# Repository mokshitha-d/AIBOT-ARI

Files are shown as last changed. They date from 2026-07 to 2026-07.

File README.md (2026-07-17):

# AI Mini Bot — DIY Kit

Build your own tiny desk robot that **talks, looks around, remembers you, and can control your Mac**.

The **ESP32 is the body** (OLED face, camera, pan/tilt servos).  
Your **computer is the brain** (OpenAI Realtime voice + ElevenLabs + local memory + head tracking).

> Illustrated guide: open [`docs/build_guide.html`](docs/build_guide.html) in a browser.

---

## What you get

- Live voice conversation (OpenAI Realtime `gpt-realtime-2`)
- Cloned / chosen voice (ElevenLabs)
- Animated OLED face (15 expressions) + web **Face Deck** at `http://<bot-ip>/`
- Pan/tilt head via PCA9685 (AI tools + autonomous glance / scan / face track)
- Local semantic memory (stays on your machine)
- Optional Mac actions (search, notes, apps, system info)

---

## Parts list

| Part | Notes |
|---|---|
| Seeed **XIAO ESP32S3 Sense** | Must be **Sense** (onboard camera) |
| 0.96" **SSD1306** OLED (I²C) | 128×64 |
| **PCA9685** 16-ch PWM board | Drives servos |
| 2× **HG90 / SG90** servos | Base = pan, neck = tilt |
| **5V 3–4A** supply | Powers PCA9685 `V+` (not from the XIAO 3V3) |
| Mac (or Linux/Windows with mic) | Runs the Python brain |

### Wiring (short version)

| From | To |
|---|----|
| OLED VCC / GND | XIAO 3V3 / GND |
| OLED SDA / SCL | XIAO **D4** / **D5** |
| PCA9685 VCC / GND | XIAO 3V3 / GND (common ground with 5V brick) |
| PCA9685 SDA / SCL | Same bus: **D4** / **D5** |
| PCA9685 V+ | External **5V** servo supply |
| Servos | PCA **CH0 = pan**, **CH1 = tilt** |

Full notes: [`hardware/README.md`](hardware/README.md).

---

## 1. Flash the body

1. Arduino IDE → ESP32 boards package  
2. **Tools:** Board `XIAO_ESP32S3`, **PSRAM = OPI PSRAM**, USB CDC On Boot = Enabled  
3. Libraries: `Adafruit GFX`, `Adafruit SSD1306`, `Adafruit PWM Servo Driver`  
4. Open `firmware/bot_face/bot_face.ino` (keep `control_page.h` beside it)  
5. Set your Wi‑Fi SSID/password near the top  
6. Upload → Serial Monitor @ **115200** → note **Bot IP**  
7. Open `http://<bot-ip>/` → Face Deck + head controls  

If upload fails at high baud, set **Upload Speed = 115200** and hold **BOOT** while resetting.

Camera off? In the sketch set `#define ENABLE_CAMERA 0`.

---

## 2. Run the brain

```bash
cd brain
python3.11 -m venv ../venv
source ../venv/bin/activate   # Windows: ..\venv\Scripts\activate
pip install -r requirements.txt
```

Copy `.env.example` → `.env` and fill:

```bash
OPENAI_API_KEY=...        # needs Realtime API access
ELEVENLABS_API_KEY=...
```

Edit `brain/bot_brain.py`:

```python
BOT_IP   = "192.168.1.XX"           # from Serial Monitor
VOICE_ID = "YOUR_ELEVENLABS_VOICE_ID"
```

From the kit root:

```bash
./run.sh
# or:  cd brain && python bot_brain.py
```

---

## Repo layout

```
diy-kit/
  firmware/bot_face/   ESP32 body (face + servos + camera + web UI)
  brain/               Mac brain (Realtime, voice, memory, head tracking)
  hardware/            Wiring notes
  docs/                Build guide
  run.sh               Launcher
  .env.example         API key template
```

---

## How it thinks

```
[ ESP32 body ]                         [ your computer — brain ]
  OLED face                              hear → Realtime → reply text
  /set  /look  /capture   ←── Wi‑Fi ──→  ElevenLabs speaks
  Face Deck web UI                       memory + Mac tools
                                         head_controller (glance/scan/track)
```

The model can call tools (`set_face`, `look`, …). A separate head loop can glance, scan the room, and track faces from camera snapshots.

---

## Security

- Never commit `.env`, Wi‑Fi passwords, or API keys  
- `.gitignore` already excludes `.env`, `venv/`, and `bot_memory/`  
- Rotate any key that leaks  

---

## License

MIT — see [LICENSE](LICENSE). Fork it, build it, make it weird.

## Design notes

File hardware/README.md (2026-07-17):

# Hardware

Breadboard prototype for the AI Mini Bot body: OLED face, camera (on Sense), and pan/tilt head via **PCA9685**.

## Parts

| Part | Role |
|---|---|
| Seeed XIAO ESP32S3 **Sense** | Brain-facing body (Wi-Fi, camera, I²C master) |
| 0.96" SSD1306 OLED | Face |
| PCA9685 16-ch PWM board | Drives servos (I²C) |
| HG90 / SG90-class servos ×2 | Base = pan (L/R), neck = tilt (U/D) |
| 5V **3–4A** supply | Powers PCA9685 `V+` (servos) — do **not** power servos from the XIAO 3V3 |

## Wiring (breadboard)

```
XIAO 3V3  ──► breadboard 3V3 rail ──► OLED VCC
                                    ──► PCA9685 VCC (logic)
XIAO GND  ──► breadboard GND      ──► OLED GND
                                    ──► PCA9685 GND
                                    ──► 5V supply GND  (common ground!)

XIAO D4 (SDA) ──► OLED SDA + PCA9685 SDA
XIAO D5 (SCL) ──► OLED SCL + PCA9685 SCL

5V supply (+) ──► PCA9685 V+ / terminal block  (servo power only)
```

### Servo channels (firmware defaults)

| PCA9685 channel | Axis | Motion |
|---|---|---|
| **CH0** | pan | base left / right |
| **CH1** | tilt | neck up / down |

Change `SERVO_CH_PAN` / `SERVO_CH_TILT` in `firmware/bot_face/bot_face.ino` if your plugs differ.

### Angles

| Pose | pan | tilt |
|---|-----|---|
| Neutral (looking at you) | 90 | 90 |
| Soft limits (first test) | 0–180 | 0–180 |

If left/right or up/down feel inverted after mounting, swap the mapping in firmware or reverse the mechanical horn.

## Power notes

- External **5V 3–4A** on the PCA9685 servo rail is required; USB alone will brown out under two HG90s.
- Keep **GND common** between XIAO, PCA9685, and the 5V brick.
- If the PCA9685 has an **OE** (output enable) pin, tie it to GND so outputs stay enabled.

## Test after flashing

1. Serial Monitor @ 115200 → note Bot IP; confirm `Servos: ready`
2. Browser: `http://<bot-ip>/` → use pan/tilt sliders + **center**
3. Or: `curl "http://<bot-ip>/look?pan=90&tilt=90"`

## 3D body

- **Model:** [`QBIT.3mf`](QBIT.3mf) (printable body)
- Optional: add a Printables / Thingiverse link here

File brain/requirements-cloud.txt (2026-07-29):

# cloud_server.py uses only the Python standard library — nothing to install.

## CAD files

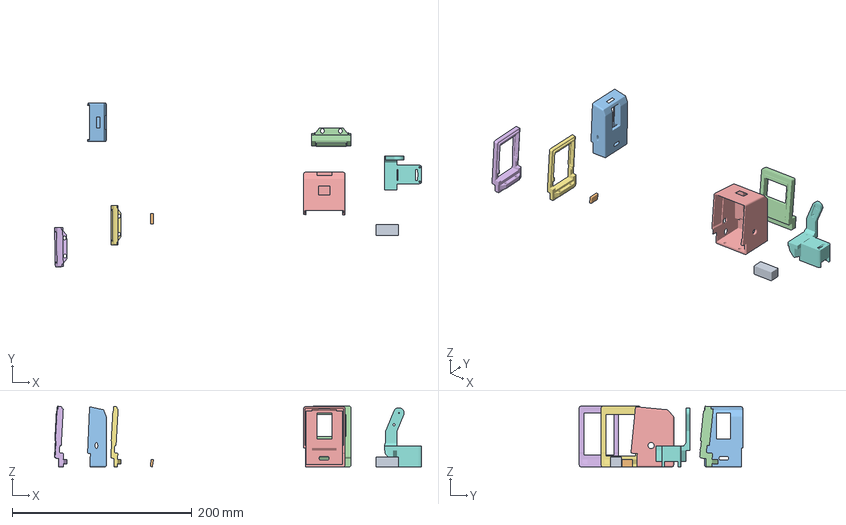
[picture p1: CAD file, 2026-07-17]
3D Model.3mf
407.9 x 182.0 x 67.4 mm
Generic-Cube_Boolean_Boolean
Generic-Cube_Boolean_Boolean_Boolean
Body_Back.stl_Boolean_Boolean_Boolean x 2
Shiny Stantia (1).stl x 3
Assembly_B_Boolean

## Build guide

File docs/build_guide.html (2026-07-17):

Open build guide · ESP32 + Mac

# A little robot that talks, sees, and remembers you.

A desk companion built from a coin-sized ESP32 with a camera and an OLED face. The board is the body; your computer is the brain. It holds a real conversation in a voice you choose, reacts to what its camera sees, remembers past chats, and can act on your Mac.

◉ Live voice

◉ Camera vision

◉ Cloned voice

◉ Long-term memory

◉ Animated face

◉ Controls your Mac

neutral

happy

thinking

searching

loading

z z

sleep

↑ the same faces the robot draws on its OLED, running live here

01

## How it works

The split that makes the whole thing possible.

The ESP32 can't run a large language model — nowhere near. So it doesn't try. The board handles the physical parts: it draws the animated face on the OLED and takes a photo when asked. Everything intelligent — hearing you, thinking, choosing words, remembering — runs in a Python program on your Mac. The two talk over your Wi-Fi.

The body

#### XIAO ESP32S3

- Draws the OLED face (15 expressions)
- Onboard camera → one photo on request
- Two tiny web endpoints: set the face, grab a frame
- Sits on your desk, powered by USB

emotion ← ⇄ → photo Wi-Fi

The brain

#### Your Mac (Python)

- Hears you, thinks, and replies as text
- Speaks the reply in a cloned voice
- Remembers every conversation, locally
- Can search, take notes, open apps, check the system

Why turn-based, not a live callThe robot listens, then speaks, with its microphone muted while it talks. This is deliberate: on laptop speakers, a fully live voice hears its own voice and cuts itself off mid-sentence. Waiting its turn is what keeps it from tripping over itself. More on this in the gotchas.

02

## What you'll need

A short list. The board does most of the heavy lifting.

Part | What it's for | Notes
Seeed XIAO ESP32S3 Sense | The whole body — Wi-Fi, camera, microphone-capable | Must be the "Sense" version — it has the camera
0.96" OLED display | The face | SSD1306, I²C, 4 pins (VCC/GND/SDA/SCL), 128×64
4 jumper wires | OLED → board | Female–female, or solder direct
USB-C cable | Power + flashing | A solid one — cheap cables cause boot brownouts
A 3D-printed body | Holds it all together | Model linked below
A Mac | The brain | Runs the Python program
Headphones (optional) | Cleaner conversations | Removes speaker→mic echo entirely

Accounts you'll needAn OpenAI key with Realtime access (the thinking + hearing), and an ElevenLabs key (the voice). Both have paid tiers — Realtime bills for audio, and a custom cloned voice via the API needs a paid ElevenLabs plan. Memory is fully local and free.

03

## Wiring the face

Four wires. The camera is already onboard — nothing to connect.

The OLED talks to the board over I²C, which needs just two data lines plus power. On the XIAO, the default I²C pins are D4 and D5.

OLED VCC

→

3V3

power

OLED GND

→

GND

ground

OLED SDA

→

D4

GPIO5 · data

OLED SCL

→

D5

GPIO6 · clock

Soldering the headerMost OLEDs ship with a loose 4-pin header. Push the pins through from the back so they poke out the labelled front, tape it flush, solder the two outer pins first, check it sits straight, then do the middle two. Insulate each joint and power-test before mounting anything into the body.

04

## Flashing the body

Load the firmware onto the ESP32 with the Arduino IDE.

### Board setup

Install the ESP32 boards package in the Arduino IDE, then set these under Tools — they matter, especially the PSRAM one:

Board | XIAO_ESP32S3
PSRAM | OPI PSRAM — required, or the camera fails to start
USB CDC On Boot | Enabled — so you get serial output

Install two libraries from the Library Manager: Adafruit GFX and Adafruit SSD1306.

### Set your Wi-Fi, then upload

Open bot_face_phase3a.ino, put in your network name and password near the top, and upload.

const char* ssid     = "your-wifi-name";
const char* password = "your-wifi-password";

Open the Serial Monitor. When it connects, it prints the robot's address — write it down, the brain needs it:

Connecting to WiFi....
Bot IP: 192.168.1.XX
Camera: ready

### Check it before moving on

Open http://<that-ip>/ in a browser. You get a little control page — tap the face buttons and watch the OLED switch expressions, and hit look to confirm the camera returns a photo. If both work, the body is done.

05

## Setting up the brain

Three Python files on your Mac do the thinking, remembering, and acting.

bot_brain_realtime.py | The main loop — hears you, thinks, speaks, drives the face
memory.py | Local semantic memory — saves and recalls past conversations
robot_actions.py | Mac actions — search, notes, open apps, system info

### Install & keys

Use a Python 3.11 environment, then:

# from the folder with the three files
python3.11 -m venv venv
source venv/bin/activate
pip install openai elevenlabs sounddevice httpx fastembed numpy

# your keys (they reset each terminal session)
export OPENAI_API_KEY="..."
export ELEVENLABS_API_KEY="..."

### Point it at your robot & voice

Near the top of bot_brain_realtime.py, set two things — the address from the Serial Monitor, and the ID of a voice you cloned in the ElevenLabs dashboard:

BOT_IP    = "192.168.1.XX"   # from Serial Monitor
VOICE_ID  = "your-cloned-voice-id"

### Run it

python bot_brain_realtime.py

First run downloads a small memory model (once), then it's listening. Everything it does prints to the console with timestamps — you can watch it hear you, look, think, and reply:

[LISTEN] you started talking
[STT]    you said: 'what time is it?'
[MEMORY] recalled 2 item(s)
[CAMERA] frame captured (10930 bytes)
[BOT]    It's just past 9 in the evening.

Keep it in one folderAll three files, and everything you run, live in a single folder. Scattered copies with the same name in different folders is the single biggest time-sink in a project like this — you edit one and run another and chase a bug that isn't there.

06

## What it can do

Beyond talking — and each action has its own face.

Say something like… | It does | Face
"Remember I train on Mondays" | Saves it to long-term memory | memory
"What did we talk about before?" | Recalls relevant past chats | memory
"Search the web for the XIAO datasheet" | Opens a browser search | searching
"Save a note about this idea" | Writes a markdown note | saving
"Open Spotify" | Launches the app | loading
"How's my laptop doing?" | Battery, storage, CPU, memory | scanning
"What's my Wi-Fi?" | Network name + IP | wifi

Memory is stored locally in plain files you can read. Mac actions run as your normal user — no admin needed — and the app-opening list is a whitelist you control.

07

## Hard-won lessons

The things that cost hours. Skip the pain.

#### The robot talks over itself

A fully live voice on laptop speakers hears its own audio through the mic and cuts off mid-sentence. Fix: mute the mic while it speaks (built in), or use headphones. Physically separating the mic and speaker is the real cure.

#### Camera won't start

"frame buffer malloc failed" means PSRAM is off. Set OPI PSRAM in the board menu and re-flash. Cold-boot flicker is usually weak USB power — use a good cable.

#### Camera image is upside down

Depends how the sensor sits. One line in the firmware flips it (set_vflip / set_hmirror). Check the photo in a browser at /capture.

#### Ghost file copies

Editing one file while running another with the same name in a different folder. One folder, one copy of each file, always.

#### The face won't change

Tap a face on the control page — if the status text updates but the OLED doesn't, it's the display; if the text doesn't update, it's the network or a wrong IP (check the Serial baud rate matches).

#### Two microphones fight

On macOS, opening the mic twice gives the second one silence. If you add wake-word or extra audio, share one mic stream.

08

## Files & links

Everything you need to build your own.

Source code (https://github.com/AyhanSh/Mac-AI-Buddy)

GitHub repo →

Firmware + the three Python files, ready to clone.

AyhanSh/Mac-AI-Buddy

3D model

Printable body →

The enclosure that holds the board and OLED.

add link

See it run

Demo video →

The robot talking, reacting, and changing faces.

add link

Before you publish your ownNever commit your Wi-Fi password or API keys. Keep them in a local .env or as environment variables, and add that file to .gitignore. If a key has ever been pasted somewhere shared, rotate it.

AI MINI BOT — open build guide

ESP32 body · Mac brain · built in public

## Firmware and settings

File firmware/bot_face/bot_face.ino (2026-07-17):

/*
  AI Mini Bot - Face + camera + pan/tilt head (PCA9685)

  Board:   Seeed XIAO ESP32S3 Sense
  Display: 0.96" SSD1306 OLED, I2C, addr 0x3C  (VCC->3V3 GND->GND SDA->D4 SCL->D5)
  Camera:  onboard OV2640 (Sense variant)
  Servos:  HG90 / SG90-class via PCA9685 on the SAME I2C bus (D4/D5)
           - external 5V 3–4A supply to PCA9685 V+ / GND
           - PCA9685 VCC -> 3V3, GND common with XIAO
           - default channels: CH0 = pan (base L/R), CH1 = tilt (neck U/D)

  Endpoints:
      GET /capture              -> single JPEG frame
      GET /look?pan=90&tilt=90  -> set head angles (0–180)
      GET /look/center          -> pan=90, tilt=90
      GET /look/status          -> current angles JSON

  Why snapshot-on-demand instead of continuous streaming:
  Running the MJPEG stream constantly alongside the OLED (I2C) and WiFi is what
  caused the DMA/resource conflicts on the intruder-alarm build. Grabbing ONE
  frame only when the Mac brain asks for it keeps the camera idle the rest of
  the time, so there's nothing to fight over.

  REQUIRED board settings:
    Board: XIAO_ESP32S3 (Sense)
    Tools > PSRAM: OPI PSRAM
    Tools > USB CDC On Boot: Enabled

  Libraries: Adafruit GFX, Adafruit SSD1306, Adafruit PWM Servo Driver

  Test after upload:
    - Serial Monitor @ 115200 for the IP
    - curl "http://<ip>/look?pan=90&tilt=90"
    - curl http://<ip>/capture --output test.jpg
    - http://<ip>/ face page + head sliders
*/

#include <Wire.h>
#include <Adafruit_GFX.h>
#include <Adafruit_SSD1306.h>
#include <Adafruit_PWMServoDriver.h>
#include <WiFi.h>
#include <WebServer.h>
#include "esp_camera.h"
#include <string.h>
#include "control_page.h"

// Set to 0 while the Sense camera is out of commission (servos/OLED still work).
#define ENABLE_CAMERA  1

// ---------- display ----------
#define SCREEN_WIDTH  128
#define SCREEN_HEIGHT 64
#define OLED_ADDR     0x3C
Adafruit_SSD1306 display(SCREEN_WIDTH, SCREEN_HEIGHT, &Wire, -1);

// ---------- wifi ----------
const char* ssid     = "YOUR_WIFI_SSID";     // <-- your network
const char* password = "YOUR_WIFI_PASSWORD";   // <-- fill this in
WebServer server(80);

// ---------- camera pins (XIAO ESP32S3 Sense) ----------
#define PWDN_GPIO_NUM     -1
#define RESET_GPIO_NUM    -1
#define XCLK_GPIO_NUM     10
#define SIOD_GPIO_NUM     40
#define SIOC_GPIO_NUM     39
#define Y9_GPIO_NUM       48
#define Y8_GPIO_NUM       11
#define Y7_GPIO_NUM       12
#define Y6_GPIO_NUM       14
#define Y5_GPIO_NUM       16
#define Y4_GPIO_NUM       18
#define Y3_GPIO_NUM       17
#define Y2_GPIO_NUM       15
#define VSYNC_GPIO_NUM    38
#define HREF_GPIO_NUM     47
#define PCLK_GPIO_NUM     13

bool cameraReady = false;
bool oledReady = false;

// ---------- head servos (PCA9685 @ 0x40 on shared I2C) ----------
// Change CH_* if your breadboard plugs pan/tilt into different PCA slots.
#define PCA9685_ADDR   0x40
#define SERVO_CH_PAN   0      // base: left / right
#define SERVO_CH_TILT  1      // neck: up / down
#define SERVO_US_MIN   500    // HG90 / SG90-ish full travel
#define SERVO_US_MAX   2500
#define PAN_CENTER     90
#define TILT_CENTER    90
#define PAN_MIN        0
#define PAN_MAX        180
#define TILT_MIN       0
#define TILT_MAX       180

Adafruit_PWMServoDriver pca = Adafruit_PWMServoDriver(PCA9685_ADDR, Wire);
bool servosReady = false;
int currentPan  = PAN_CENTER;
int currentTilt = TILT_CENTER;

// ---------- emotion state ----------
enum Emotion { NEUTRAL, HAPPY, SAD, ANGRY, SURPRISED, THINKING, LISTENING, TALKING, SLEEP,
               SEARCHING, LOADING, SCANNING, WIFI, MEMORY, SAVING };
Emotion current = NEUTRAL;

// ---------- timing ----------
unsigned long lastFrame = 0;
const int FRAME_MS = 33;

// ---------- blink ----------
bool blinking = false;
unsigned long blinkStart = 0;
unsigned long nextBlink = 0;
const int BLINK_MS = 180;

// ---------- geometry ----------
const int CX = 64, CY = 32;
const int EYE_W = 34, EYE_H = 40, EYE_R = 10;
const int EYE_GAP = 20;

float blinkOpenness() {
  if (!blinking) return 1.0;
  unsigned long e = millis() - blinkStart;
  if (e >= (unsigned long)BLINK_MS) { blinking = false; return 1.0; }
  float t = (float)e / BLINK_MS;
  return fabs(t - 0.5) * 2.0;
}

void drawOpenEyes(float hScale, int yOffset, int wDelta) {
  int h = (int)(EYE_H * hScale);
  if (h < 4) h = 4;
  int w = EYE_W + wDelta;
  int y  = CY - h / 2 + yOffset;
  int lx = CX - EYE_GAP / 2 - w;
  int rx = CX + EYE_GAP / 2;
  display.fillRoundRect(lx, y, w, h, EYE_R, SSD1306_WHITE);
  display.fillRoundRect(rx, y, w, h, EYE_R, SSD1306_WHITE);
}

void drawHappyEyes() {
  int r = 18, y = CY - 2;
  int lcx = CX - EYE_GAP / 2 - r;
  int rcx = CX + EYE_GAP / 2 + r;
  display.fillCircle(lcx, y, r, SSD1306_WHITE);
  display.fillCircle(rcx, y, r, SSD1306_WHITE);
  display.fillRect(0, y, SCREEN_WIDTH, r + 3, SSD1306_BLACK);
}

void drawSurprisedEyes() {
  int r = 19;
  int lcx = CX - EYE_GAP / 2 - r + 3;
  int rcx = CX + EYE_GAP / 2 + r - 3;
  int y = CY;
  display.fillCircle(lcx, y, r, SSD1306_WHITE);
  display.fillCircle(rcx, y, r, SSD1306_WHITE);
  display.fillCircle(lcx, y, r / 2, SSD1306_BLACK);
  display.fillCircle(rcx, y, r / 2, SSD1306_BLACK);
}

void drawAngryEyes() {
  int h = 40, w = 34, y = CY - h / 2 + 2;
  int lx = CX - EYE_GAP / 2 - w;
  int rx = CX + EYE_GAP / 2;
  display.fillRoundRect(lx, y, w, h, EYE_R, SSD1306_WHITE);
  display.fillRoundRect(rx, y, w, h, EYE_R, SSD1306_WHITE);
  int cw = 26, ch = 20;
  display.fillTriangle(lx + w, y, lx + w - cw, y, lx + w, y + ch, SSD1306_BLACK);
  display.fillTriangle(rx,     y, rx + cw,     y, rx,     y + ch, SSD1306_BLACK);
}

void drawSadEyes() {
  int h = 30, w = 34, y = CY - h / 2 + 6;
  int lx = CX - EYE_GAP / 2 - w;
  int rx = CX + EYE_GAP / 2;
  display.fillRoundRect(lx, y, w, h, EYE_R, SSD1306_WHITE);
  display.fillRoundRect(rx, y, w, h, EYE_R, SSD1306_WHITE);
  int cw = 26, ch = 20;
  display.fillTriangle(lx,     y, lx + cw,     y, lx,     y + ch, SSD1306_BLACK);
  display.fillTriangle(rx + w, y, rx + w - cw, y, rx + w, y + ch, SSD1306_BLACK);
}

void drawThinkingEyes() {
  int h = 26, w = 34, xs = 6, ys = -4;
  int y  = CY - h / 2 + ys;
  int lx = CX - EYE_GAP / 2 - w + xs;
  int rx = CX + EYE_GAP / 2 + xs;
  display.fillRoundRect(lx, y, w, h, EYE_R, SSD1306_WHITE);
  display.fillRoundRect(rx, y, w, h, EYE_R, SSD1306_WHITE);
}

void drawSleepEyes() {
  int w = 34, y = CY;
  int lx = CX - EYE_GAP / 2 - w;
  int rx = CX + EYE_GAP / 2;
  display.fillRoundRect(lx, y - 2, w, 5, 2, SSD1306_WHITE);
  display.fillRoundRect(rx, y - 2, w, 5, 2, SSD1306_WHITE);
  display.setTextColor(SSD1306_WHITE);
  display.setTextSize(1);
  display.setCursor(98, 8);  display.print("z");
  display.setCursor(106, 0); display.print("z");
}

// shared: eyes with an x/y shift and height scale (used by the action faces)
void drawEyesShift(int xs, int ys, float hScale) {
  int h = (int)(EYE_H * hScale);
  if (h < 4) h = 4;
  int w = EYE_W;
  int y  = CY - h / 2 + ys;
  int lx = CX - EYE_GAP / 2 - w + xs;
  int rx = CX + EYE_GAP / 2 + xs;
  display.fillRoundRect(lx, y, w, h, EYE_R, SSD1306_WHITE);
  display.fillRoundRect(rx, y, w, h, EYE_R, SSD1306_WHITE);
}

// SEARCHING (web search): eyes dart side to side, scanning
void drawSearching() {
  int xs = (int)(14 * sin(millis() / 180.0));
  drawEyesShift(xs, 0, 0.8);
}

// LOADING (opening app / generic work): a comet-head spinner ring
void drawLoading() {
  int r = 16, dots = 12;
  int head = (int)(millis() / 80) % dots;
  for (int i = 0; i < dots; i++) {
    float a = (2 * PI * i) / dots;
    int x = CX + (int)(r * cos(a));
    int y = CY + (int)(r * sin(a));
    int dist = (i - head + dots) % dots;
    int rad = (dist == 0) ? 3 : (dist == 1 ? 2 : (dist == 2 ? 1 : 0));
    if (rad > 0) display.fillCircle(x, y, rad, SSD1306_WHITE);
  }
}

// SCANNING (system status): focused eyes + a scan bar sweeping across
void drawScanning() {
  drawEyesShift(0, 0, 0.55);
  int x = (int)(CX + 60 * sin(millis() / 300.0));
  display.drawFastVLine(x, 0, SCREEN_HEIGHT, SSD1306_WHITE);
}

// WIFI (network check): pulsing wifi arcs rising from a base dot
void drawWifi() {
  int by = 46;
  display.fillCircle(CX, by, 3, SSD1306_WHITE);
  int phase = (int)(millis() / 300) % 4;
  for (int k = 1; k <= 3; k++) {
    if (k <= phase) {
      int rr = k * 11;
      for (int deg = 225; deg <= 315; deg += 5) {
        float a = deg * PI / 180.0;
        int x = CX + (int)(rr * cos(a));
        int y = by + (int)(rr * sin(a));
        display.drawPixel(x, y, SSD1306_WHITE);
      }
    }
  }
}

// MEMORY (remember / recall / forget): eyes glance up, thought dots rise
void drawMemory() {
  drawEyesShift(-6, -3, 0.8);
  int phase = (int)(millis() / 250) % 3;
  int bx = 98, by = 22;
  for (int i = 0; i < 3; i++) {
    if (i <= phase) display.fillCircle(bx + i * 7, by - i * 7, (i == 2 ? 1 : 2), SSD1306_WHITE);
  }
}

// SAVING (save note): eyes + a cycling progress bar
void drawSaving() {
  drawEyesShift(0, -5, 0.7);
  int w = 80, x = (SCREEN_WIDTH - w) / 2, y = 52, h = 7;
  display.drawRoundRect(x, y, w, h, 2, SSD1306_WHITE);
  int fill = (int)(millis() / 18) % (w - 2);
  display.fillRect(x + 1, y + 1, fill, h - 2, SSD1306_WHITE);
}

void renderFace() {
  display.clearDisplay();
  switch (current) {
    case NEUTRAL:
      drawOpenEyes(blinkOpenness(), 0, 0);
      break;
    case LISTENING: {
      float pulse = 1.0 + 0.06 * sin(millis() / 250.0);
      drawOpenEyes(blinkOpenness() * pulse, 0, 2);
      break;
    }
    case TALKING: {
      int bob = (int)(2 * sin(millis() / 90.0));
      drawOpenEyes(blinkOpenness(), bob, 0);
      break;
    }
    case HAPPY:     drawHappyEyes();     break;
    case SAD:       drawSadEyes();       break;
    case ANGRY:     drawAngryEyes();     break;
    case SURPRISED: drawSurprisedEyes(); break;
    case THINKING:  drawThinkingEyes();  break;
    case SLEEP:     drawSleepEyes();     break;
    case SEARCHING: drawSearching();     break;
    case LOADING:   drawLoading();       break;
    case SCANNING:  drawScanning();      break;
    case WIFI:      drawWifi();          break;
    case MEMORY:    drawMemory();        break;
    case SAVING:    drawSaving();        break;
  }
  display.display();
}

void updateBlink() {
  if (current != NEUTRAL && current != LISTENING && current != TALKING) return;
  unsigned long now = millis();
  if (!blinking && now > nextBlink) {
    blinking = true;
    blinkStart = now;
    nextBlink = now + random(2500, 6000);
  }
}

// ---------- camera ----------
// 0x106 = ESP_ERR_NOT_SUPPORTED → sensor probe failed / bad config.
// Newer Arduino-ESP32 BSPs added fields to camera_config_t; leaving them
// uninitialized often causes exactly this. Zero the struct, keep SCCB on
// I2C port 1 so it never fights Wire (OLED + PCA9685 on port 0 / D4+D5).
bool initCameraOnce(int xclk_hz) {
  camera_config_t config;
  memset(&config, 0, sizeof(config));

  config.ledc_channel = LEDC_CHANNEL_0;
  config.ledc_timer   = LEDC_TIMER_0;
  config.pin_d0 = Y2_GPIO_NUM;  config.pin_d1 = Y3_GPIO_NUM;
  config.pin_d2 = Y4_GPIO_NUM;  config.pin_d3 = Y5_GPIO_NUM;
  config.pin_d4 = Y6_GPIO_NUM;  config.pin_d5 = Y7_GPIO_NUM;
  config.pin_d6 = Y8_GPIO_NUM;  config.pin_d7 = Y9_GPIO_NUM;
  config.pin_xclk  = XCLK_GPIO_NUM;
  config.pin_pclk  = PCLK_GPIO_NUM;
  config.pin_vsync = VSYNC_GPIO_NUM;
  config.pin_href  = HREF_GPIO_NUM;
  config.pin_sccb_sda = SIOD_GPIO_NUM;
  config.pin_sccb_scl = SIOC_GPIO_NUM;
  config.pin_pwdn  = PWDN_GPIO_NUM;
  config.pin_reset = RESET_GPIO_NUM;
  config.xclk_freq_hz = xclk_hz;
  config.pixel_format = PIXFORMAT_JPEG;
  config.frame_size   = FRAMESIZE_VGA;
  config.jpeg_quality = 12;
  config.grab_mode    = CAMERA_GRAB_WHEN_EMPTY;
#if defined(CAMERA_FB_IN_PSRAM)
  config.fb_location  = CAMERA_FB_IN_PSRAM;
#endif

  if (psramFound()) {
    config.fb_count = 2;
  } else {
    config.fb_count = 1;
  }

  esp_err_t err = esp_camera_init(&config);
  if (err != ESP_OK) {
    Serial.printf("Camera init failed: 0x%x (xclk=%dHz)\n", err, xclk_hz);
    return false;
  }
  return true;
}

bool initCamera() {
  Serial.printf("PSRAM: %s\n", psramFound() ? "found" : "NOT found (set Tools > PSRAM = OPI PSRAM)");
  delay(300);   // Sense cam ribbon is picky on cold boot / after upload

  // Single init only — esp_camera_init is effectively one-shot on many BSPs.
  if (!initCameraOnce(20000000)) {
    Serial.println("Camera probe failed (0x106 = sensor ID not recognized).");
    Serial.println("This is usually: loose Sense ribbon, OR Arduino ESP32 core 3.x bug.");
    Serial.println("Fix: reseat camera FPC, then try Boards Manager -> esp32 -> 2.0.14");
    return false;
  }

  sensor_t* s = esp_camera_sensor_get();
  if (s) {
    s->set_vflip(s, 1);    // flip vertically - fixes upside-down image
    s->set_hmirror(s, 0);  // set to 1 instead if it's mirrored left-right rather than upside-down
  }
  Serial.println("Camera: init ok");
  return true;
}

// ---------- servos ----------
int clampInt(int v, int lo, int hi) {
  if (v < lo) return lo;
  if (v > hi) return hi;
  return v;
}

int angleToUs(int angle) {
  angle = clampInt(angle, 0, 180);
  return SERVO_US_MIN + (angle * (SERVO_US_MAX - SERVO_US_MIN)) / 180;
}

void scanI2C() {
  Serial.println("I2C scan (D4=SDA, D5=SCL):");
  int n = 0;
  for (uint8_t addr = 1; addr < 127; addr++) {
    Wire.beginTransmission(addr);
    if (Wire.endTransmission() == 0) {
      Serial.printf("  found 0x%02X", addr);
      if (addr == OLED_ADDR) Serial.print("  (OLED)");
      if (addr == PCA9685_ADDR) Serial.print("  (PCA9685)");
      Serial.println();
      n++;
    }
  }
  if (n == 0) Serial.println("  nothing found — check 3V3/GND/SDA/SCL");
  Serial.println("Expect OLED 0x3C/0x3D + PCA 0x40. 0x70=PCA all-call OK. Ghost 0x01 => flaky bus/pull-ups.");
}


// Drive a channel with setPWM (more reliable across PCA9685 clones than us helpers).
void writeServoAngle(uint8_t ch, int angle) {
  int us = angleToUs(angle);
  // Prefer library us helper; also poke setPWM for stubborn clones.
  pca.writeMicroseconds(ch, us);
  uint16_t tick = (uint16_t)(((uint32_t)us * 4096UL) / 20000UL);
  if (tick < 1) tick = 1;
  if (tick > 4095) tick = 4095;
  pca.setPWM(ch, 0, tick);
  Serial.printf("servo CH%d -> %d deg (%dus / tick %u)\n", ch, angle, us, tick);
}

bool initServos() {
  // Older Adafruit_PWMServoDriver: begin(prescale=0). Address comes from the constructor.
  if (!pca.begin()) {
    Serial.println("PCA9685 not found on I2C - check wiring / address 0x40");
    return false;
  }
  // Cheap PCA9685 boards often need this or pulse widths are wrong / no motion.
  pca.setOscillatorFrequency(27000000);
  pca.setPWMFreq(50);   // hobby servo rate
  delay(20);

  currentPan  = PAN_CENTER;
  currentTilt = TILT_CENTER;
  writeServoAngle(SERVO_CH_PAN,  currentPan);
  writeServoAngle(SERVO_CH_TILT, currentTilt);
  delay(300);

  // Visible boot self-test — if you see no motion here, it's power/wiring/channel.
  Serial.println("Servo wiggle test (CH0 pan, CH1 tilt)...");
  writeServoAngle(SERVO_CH_PAN,  70);
  delay(250);
  writeServoAngle(SERVO_CH_PAN, 110);
  delay(250);
  writeServoAngle(SERVO_CH_PAN,  PAN_CENTER);
  writeServoAngle(SERVO_CH_TILT, 70);
  delay(250);
  writeServoAngle(SERVO_CH_TILT, 110);
  delay(250);
  writeServoAngle(SERVO_CH_TILT, TILT_CENTER);

  Serial.printf("Servos: ready (pan CH%d, tilt CH%d) centered at %d/%d\n",
                SERVO_CH_PAN, SERVO_CH_TILT, currentPan, currentTilt);
  Serial.println("If no wiggle: check 5V on PCA V+/terminal, common GND, OE low, servo plugs on CH0/CH1");
  return true;
}

void setHead(int pan, int tilt) {
  currentPan  = clampInt(pan,  PAN_MIN,  PAN_MAX);
  currentTilt = clampInt(tilt, TILT_MIN, TILT_MAX);
  if (!servosReady) return;
  writeServoAngle(SERVO_CH_PAN,  currentPan);
  writeServoAngle(SERVO_CH_TILT, currentTilt);
}

void handleCapture() {
  if (!cameraReady) {
    server.send(503, "text/plain", "camera not ready");
    return;
  }
  camera_fb_t* fb = esp_camera_fb_get();
  if (!fb) {
    server.send(500, "text/plain", "capture failed");
    return;
  }
  server.setContentLength(fb->len);
  server.send(200, "image/jpeg", "");
  WiFiClient client = server.client();
  client.write(fb->buf, fb->len);
  esp_camera_fb_return(fb);
}

void handleLook() {
  // Accept any combo of pan / tilt; missing args keep the current angle.
  Serial.printf("LOOK req args pan=%s tilt=%s\n",
                server.hasArg("pan") ? server.arg("pan").c_str() : "-",
                server.hasArg("tilt") ? server.arg("tilt").c_str() : "-");
  int pan  = server.hasArg("pan")  ? server.arg("pan").toInt()  : currentPan;
  int tilt = server.hasArg("tilt") ? server.arg("tilt").toInt() : currentTilt;
  if (!servosReady) {
    server.send(503, "text/plain", "servos not ready");
    return;
  }
  setHead(pan, tilt);
  String body = "ok:pan=" + String(currentPan) + ",tilt=" + String(currentTilt);
  server.send(200, "text/plain", body);
  Serial.println(body);
}

void handleLookCenter() {
  if (!servosReady) {
    server.send(503, "text/plain", "servos not ready");
    return;
  }
  setHead(PAN_CENTER, TILT_CENTER);
  server.send(200, "text/plain", "ok:center");
  Serial.println("ok:center");
}

void handleLookStatus() {
  String j = "{\"pan\":" + String(currentPan) +
             ",\"tilt\":" + String(currentTilt) +
             ",\"ready\":" + String(servosReady ? "true" : "false") + "}";
  server.send(200, "application/json", j);
}

// ---------- web ----------
Emotion parseEmotion(String s) {
  s.toLowerCase();
  if (s == "neutral")   return NEUTRAL;
  if (s == "happy")     return HAPPY;
  if (s == "sad")       return SAD;
  if (s == "angry")     return ANGRY;
  if (s == "surprised") return SURPRISED;
  if (s == "thinking")  return THINKING;
  if (s == "listening") return LISTENING;
  if (s == "talking")   return TALKING;
  if (s == "sleep")     return SLEEP;
  if (s == "searching") return SEARCHING;
  if (s == "loading")   return LOADING;
  if (s == "scanning")  return SCANNING;
  if (s == "wifi")      return WIFI;
  if (s == "memory")    return MEMORY;
  if (s == "saving")    return SAVING;
  return NEUTRAL;
}

void handleSet() {
  if (!server.hasArg("e")) { server.send(400, "text/plain", "missing e"); return; }
  current = parseEmotion(server.arg("e"));
  server.send(200, "text/plain", "ok:" + server.arg("e"));
}

void handleRoot() {
  // Fancy animated control deck lives in flash (control_page.h).
  server.send_P(200, "text/html", CONTROL_PAGE);
}

void setupRoutes() {
  server.on("/", handleRoot);
  server.on("/set", handleSet);
  server.on("/capture", handleCapture);
  // Register /look/* BEFORE /look so the longer paths win on picky WebServer builds.
  server.on("/look/center", HTTP_GET, handleLookCenter);
  server.on("/look/status", HTTP_GET, handleLookStatus);
  server.on("/look", HTTP_GET, handleLook);
  auto reg = [](const char* p, Emotion e) {
    server.on(p, [e]() { current = e; server.send(200, "text/plain", "ok"); });
  };
  reg("/neutral", NEUTRAL);   reg("/happy", HAPPY);       reg("/sad", SAD);
  reg("/angry", ANGRY);       reg("/surprised", SURPRISED); reg("/thinking", THINKING);
  reg("/listening", LISTENING); reg("/talking", TALKING);  reg("/sleep", SLEEP);
  reg("/searching", SEARCHING); reg("/loading", LOADING);  reg("/scanning", SCANNING);
  reg("/wifi", WIFI);         reg("/memory", MEMORY);      reg("/saving", SAVING);
}

void setup() {
  Serial.begin(115200);
  delay(800);   // USB CDC needs a moment after reset before logs

#if ENABLE_CAMERA
  cameraReady = initCamera();   // camera BEFORE Wire if enabled
  if (!cameraReady) {
    Serial.println("Continuing without camera - face still works, /capture will 503");
  }
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
void loop() {
  server.handleClient();
  unsigned long now = millis();
  if (oledReady && now - lastFrame >= (unsigned long)FRAME_MS) {
    lastFrame = now;
    updateBlink();
    renderFace();
  }
}

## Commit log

2026-07-17 v1.5 Update - moving body and face tracking
    [3D Model.3mf, QBIT(4).3mf]
2026-07-28 Add landing page for GitHub Pages
2026-07-29 Add cloud backend for real AI replies via Groq, wire up frontend fallback
2026-08-07 Turn Ari into a vibe guide / confidence coach with personalized theming
    Adds a Vibe / Emotional Support mode toggle, a get-to-know-you onboarding
    flow (name, likes, goals, picture preferences, vibe word), and applies a
    Groq-generated color theme plus keyword-matched background photos based on
    the answers. Removes voice chat UI and emojis in favor of a clean text chat.
